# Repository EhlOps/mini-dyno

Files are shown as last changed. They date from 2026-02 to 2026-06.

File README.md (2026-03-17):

# Mini Dyno

### Overview

The mini dyno (dynamometer) is a tool created to measure the torque and power output of an engine or motor. The mechanical portion of the dyno functions as a water brake. This design is suited for engines up to 4 horsepower and is mainly used to measure the output of small engines used in RC cars.

An ESP32-C3 microcontroller reads a load cell (via HX711 ADC) and a Hall effect RPM sensor, converts the readings to torque (Nm) and RPM, then streams them over WiFi to an iOS companion app. The app plots a traditional dyno graph — torque and power vs RPM — in real time.

---

## System Architecture

```
Engine ──── Water Brake ──── Load Cell ──── HX711 ────┐
                  │                                   ESP32-C3 ── WiFi AP ── iPhone
              Hall Sensor (4 magnets/rev) ─────────────┘
```

| Measurement | Sensor | Pin |
|---|---|---|
| Force (→ Torque) | HX711 load cell ADC | PD_SCK: GPIO 7, DOUT: GPIO 6 |
| RPM | Digital Hall effect | GPIO 10 |
| Ready indicator | LED | GPIO 5 |

**Torque arm:** 100 mm (load cell to shaft centre)
**Torque (Nm):** `Force (N) × 0.1 m`
**Power (hp):** `Torque (Nm) × RPM × 2π / 60 / 745.7`

---

## Repository Structure

```
mini-dyno/
├── firmware/   — ESP-IDF project for ESP32-C3
└── software/   — iOS companion app (Xcode / SwiftUI)
```

See the README in each subdirectory for build and usage instructions.

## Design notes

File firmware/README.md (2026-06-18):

# mini-dyno firmware

Firmware for the **mini-dyno**, a small water-brake dynamometer. It runs on an
**ESP32-C3**, stands up an open Wi-Fi access point, and serves live torque/RPM
telemetry to connected clients over a tiny built-in MQTT broker. A phone or
laptop joins the AP, subscribes, and plots the dyno run in real time.

Written in async Rust (`no_std`) on [`esp-hal`] and [`embassy`].

[`esp-hal`]: https://docs.rs/esp-hal
[`embassy`]: https://embassy.dev

## Read the docs (the guided tour)

The whole codebase is documented as rustdoc — the module headers read top to
bottom as an explanation of *why* the firmware is shaped the way it is. The
best way to understand it is to generate the docs and browse them:

```sh
cargo doc --no-deps --open
```

This builds the API docs for just this crate and opens them in your browser
(`target/riscv32imc-unknown-none-elf/doc/firmware/index.html`). Drop
`--no-deps` if you also want the docs for `esp-hal`, `embassy`, `smoltcp`, etc.
linked inline — that's a much bigger build, but every type cross-links to its
upstream definition.

Suggested reading order, following the links as you go:

1. **`firmware`** (crate root) — the one-paragraph map of the modules.
2. **`firmware::net`** — bringing up the Wi-Fi AP and the `embassy-net` stack;
   start with the `Net` type.
3. **`firmware::net::mqtt`** — the payload-agnostic MQTT 3.1.1/5 broker, its
   concurrency model (`Feed` / `Watch`), and the per-connection state machine.
4. **`firmware::drivers`** — the sensor drivers and their read loops:
   `drivers::hx711` (load-cell ADC, bit-banged) and `drivers::hall_effect`
   (interrupt-driven RPM pickup), each republishing on a `Signal`.
5. **`firmware::telemetry`** — the `Telemetry` sample type, its JSON wire
   format, and the producer task that latches the driver signals and feeds the
   broker.
6. **`firmware::macros`** — `mk_static!`, the `'static`-allocation helper the
   embassy tasks lean on.

> The binary entry point (`src/bin/main.rs`) is a separate bin crate, so it
> isn't part of the `firmware` library docs above. Its boot sequence is
> documented in the file's own `//!` header.

## Build & flash

Prerequisites:

- A Rust toolchain — the pinned channel and the RISC-V target are declared in
  [`rust-toolchain.toml`](rust-toolchain.toml) and installed automatically by `rustup`.
- [`espflash`](https://github.com/esp-rs/espflash) (`cargo install espflash`)
  for flashing over USB; it's already wired up as the cargo runner.

```sh
cargo build --release        # compile
cargo run                    # flash + monitor (defmt) over USB
cargo run --release          # same, optimized
```

The target (`riscv32imc-unknown-none-elf`) and the `espflash` runner are
configured in [`.cargo/config.toml`](.cargo/config.toml), so plain `cargo run`
just works. You can also simulate the firmware without hardware via
[Wokwi](https://wokwi.com) — see [`wokwi.toml`](wokwi.toml) and
[`diagram.json`](diagram.json).

## Connecting a client

1. Join the open Wi-Fi network **`mini-dyno`**.
2. Point an MQTT client at `192.168.1.1:1883` and subscribe to `dyno/telemetry`.
3. You'll receive a JSON payload per sample: `{"torque":<n.nn>,"rpm":<n>}`.

## Status

Both sensors are wired in and read live: the hall-effect driver
(`drivers::hall_effect`, GPIO10) reports real RPM, and the HX711 load-cell
driver (`drivers::hx711`, GPIO6/7) streams real ADC samples. **Calibration is
still pending** — `telemetry::producer` currently passes the raw 24-bit HX711
word straight through as the `torque` field, so that number is a placeholder
until an offset/scale (tare + N·m per count) is applied.

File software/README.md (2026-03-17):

# Dyno Monitor — iOS App

iOS companion app for the mini-dyno dynamometer. Connects to the ESP32 over WiFi, streams live torque and RPM readings, plots a traditional dyno graph (torque + power vs RPM) in real time, and exports session data as CSV or PNG.

## Requirements

- iOS 16+
- Xcode 15+
- mini-dyno ESP32 device running the firmware

## How It Works

The ESP32 runs a WiFi access point (`mini-dyno`, open network) and a WebSocket server. The app connects to `ws://192.168.4.1/ws` and receives JSON frames at 50 Hz:

```json
{"torque": 12.45, "rpm": 3200}
```

| Field | Type | Description |
|---|---|---|
| `torque` | float | Torque in Newton-metres |
| `rpm` | float | Engine speed in RPM |

Power is computed in the app: `P (hp) = torque (Nm) × rpm × 2π / 60 / 745.7`

The app plots both torque (Nm, red) and power (hp, blue) against RPM on the same chart, matching a traditional dyno sheet.

## Getting Started

1. Flash the ESP32 firmware (see `../firmware/`)
2. On your iPhone/iPad, go to **Settings → Wi-Fi** and join the `mini-dyno` network
3. Open the app — the connection indicator turns green when the device is reachable
4. Tap **Start** to begin recording, **Stop** to end the session

## App Structure

```
software/
├── Models/
│   ├── DynoDataPoint.swift     — single sample: rpm, torqueNm, computed powerHp
│   └── DynoSession.swift       — recording session; tracks peak torque, peak power, RPM at peaks
├── Services/
│   ├── WebSocketService.swift  — URLSession WebSocket client; parses {"torque","rpm"} frames
│   ├── NetworkMonitor.swift    — polls GET /ping every 2 s to track connectivity
│   └── DataExporter.swift      — exports CSV and graph PNG to the temp directory
├── View Models/
│   └── DynoViewModel.swift     — app state; bridges WebSocket → session data points
├── Utilities/
│   └── AppConfiguration.swift  — network URLs, timing constants, feature flags
└── Views/
    ├── ContentView.swift        — adaptive layout: graph + controls
    ├── ConnectionStatusView.swift
    ├── DynoGraphView.swift      — SwiftUI Charts: torque (red) + power (blue) vs RPM
    ├── StatsView.swift          — peak torque, peak power (with RPM subtitles), point count
    ├── DetailedStatsView.swift  — full run report with export button
    ├── SavedSessionsView.swift  — history list; swipe to delete or export
    └── SettingsView.swift       — edit WebSocket/ping URLs; reset to defaults
```

## UI Overview

The main screen uses an adaptive two-column layout in landscape:

- **Left** — live connection status badge + dyno graph
- **Right** — Start / Stop / Clear / Stats buttons

The toolbar provides access to **Settings** (gear icon, top-left) and **Session History** (clock icon, top-right).

### Settings

| Setting | Default |
|---|---|
| WebSocket URL | `ws://192.168.4.1/ws` |
| Device Ping URL | `http://192.168.4.1/ping` |

### Session History

Completed sessions are listed in reverse chronological order showing peak torque, peak power, and point count. Swipe left to **Export** (CSV + graph PNG) or swipe right to **Delete**.

## Export Format

**CSV** — one row per sample, plus a summary block:

```
Timestamp,RPM,Torque (Nm),Power (hp)
12:34:56.001,1200,42.30,9.65
12:34:56.021,1260,44.80,10.72
...

Summary
Peak Torque (Nm),82.0
Peak Power (hp),38.42
RPM at Peak Torque,3500
RPM at Peak Power,4800
```

**Graph PNG** — 1200×800 px at 2× scale (2400×1600 effective).

## Debug Build

In debug builds a **Test Data** button appears on the main screen. It generates a simulated dyno pull from 1000 to 6000 RPM with a Gaussian torque curve peaking at 85 Nm near 3500 RPM, so the UI can be exercised without hardware.

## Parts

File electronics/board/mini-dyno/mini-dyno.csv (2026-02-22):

Reference | Qty | Value | DNP | Exclude from BOM | Exclude from Board | Footprint | Datasheet
C1,C5,C6,C8,C9 | 5 | 10uF |  |  |  | Capacitor_SMD:C_0805_2012Metric | ~
C2,C4,C7,C10,C12 | 5 | 0.1uF |  |  |  | Capacitor_SMD:C_0805_2012Metric | ~
C3 | 1 | 1uF |  |  |  | Capacitor_SMD:C_0805_2012Metric | ~
C11 | 1 | 35ZLH100MEFC6.3X11 |  |  |  | easyeda2kicad:CAP-TH_BD6.3-P2.50-D1.0-FD | https://lcsc.com/product-detail/Aluminum-Electrolytic-Capacitors-Leaded_Rubycon_35ZLH100MEFC6-3X1_100uF-107-20-35V_C109392.html
D1 | 1 | ESD122DMYR |  |  |  | easyeda2kicad:X2SON-3_L1.3-W0.6-L
D2 | 1 | SMBJ5.0A_C83333 |  |  |  | easyeda2kicad:SMB_L4.6-W3.6-LS5.3-RD | https://lcsc.com/product-detail/Others_Littelfuse_SMBJ5-0A_Littelfuse-SMBJ5-0A_C83333.html
D3 | 1 | LED_ON |  |  |  | LED_THT:LED_D5.0mm | ~
D4 | 1 | LED_STATUS |  |  |  | LED_THT:LED_D5.0mm | ~
D5 | 1 | SS310_C14281 |  |  |  | easyeda2kicad:SMB_L4.6-W3.6-LS5.3-RD | https://lcsc.com/product-detail/Schottky-Barrier-Diodes-SBD_SS310_C14281.html
F1 | 1 | TLC-PSML400 |  |  |  | easyeda2kicad:F0805
J1 | 1 | Conn_01x04_Pin |  |  |  | Connector_PinHeader_2.54mm:PinHeader_1x04_P2.54mm_Horizontal | ~
J2 | 1 | Conn_01x03_Pin |  |  |  | Connector_PinHeader_2.54mm:PinHeader_1x03_P2.54mm_Horizontal | ~
MOTOR1 | 1 | 916-252A2023Y10200 |  |  |  | easyeda2kicad:USB-A-TH_916-352A102BY10200
R1,R5,R6,R7,R11,R13 | 6 | 10kΩ |  |  |  | Resistor_SMD:R_0805_2012Metric | ~
R2,R3,R4,R9 | 4 | 5.1kΩ |  |  |  | Resistor_SMD:R_0805_2012Metric | ~
R8,R10 | 2 | 1MΩ |  |  |  | Resistor_SMD:R_0805_2012Metric | ~
R12,R14,R15,R16 | 4 | 100Ω |  |  |  | Resistor_SMD:R_0805_2012Metric | ~
SW1,SW2 | 2 | SW_Push |  |  |  | Button_Switch_SMD:SW_Push_1P1T_NO_E-Switch_TL3301NxxxxxG | ~
U1 | 1 | ESP32-C3-MINI-1 |  |  |  | PCM_Espressif:ESP32-C3-MINI-1 | https://www.espressif.com/sites/default/files/documentation/esp32-c3-mini-1_datasheet_en.pdf
U2 | 1 | TLV75733PDBVR |  |  |  | easyeda2kicad:SOT-23-5_L2.9-W1.6-P0.95-LS2.8-BL | https://lcsc.com/product-detail/New-Arrivals_Texas-Instruments-Texas-Instruments-TLV75733PDBVR_C485517.html
U4 | 1 | HX711_C6705483 |  |  |  | easyeda2kicad:SOP-16_L10.0-W3.9-P1.27-LS6.0-BL
USB1,USB3 | 2 | MC-710A |  |  |  | easyeda2kicad:USB-C-TH_MC-710A

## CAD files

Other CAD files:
mechanical/parts/Rotor.step
mechanical/parts/Rotor Housing.step
mechanical/parts/Stator.step
mechanical/parts/Bearing Housing.step
mechanical/parts/Holder.step
mechanical/parts/Load Cell Base.step
mechanical/parts/Collar.step

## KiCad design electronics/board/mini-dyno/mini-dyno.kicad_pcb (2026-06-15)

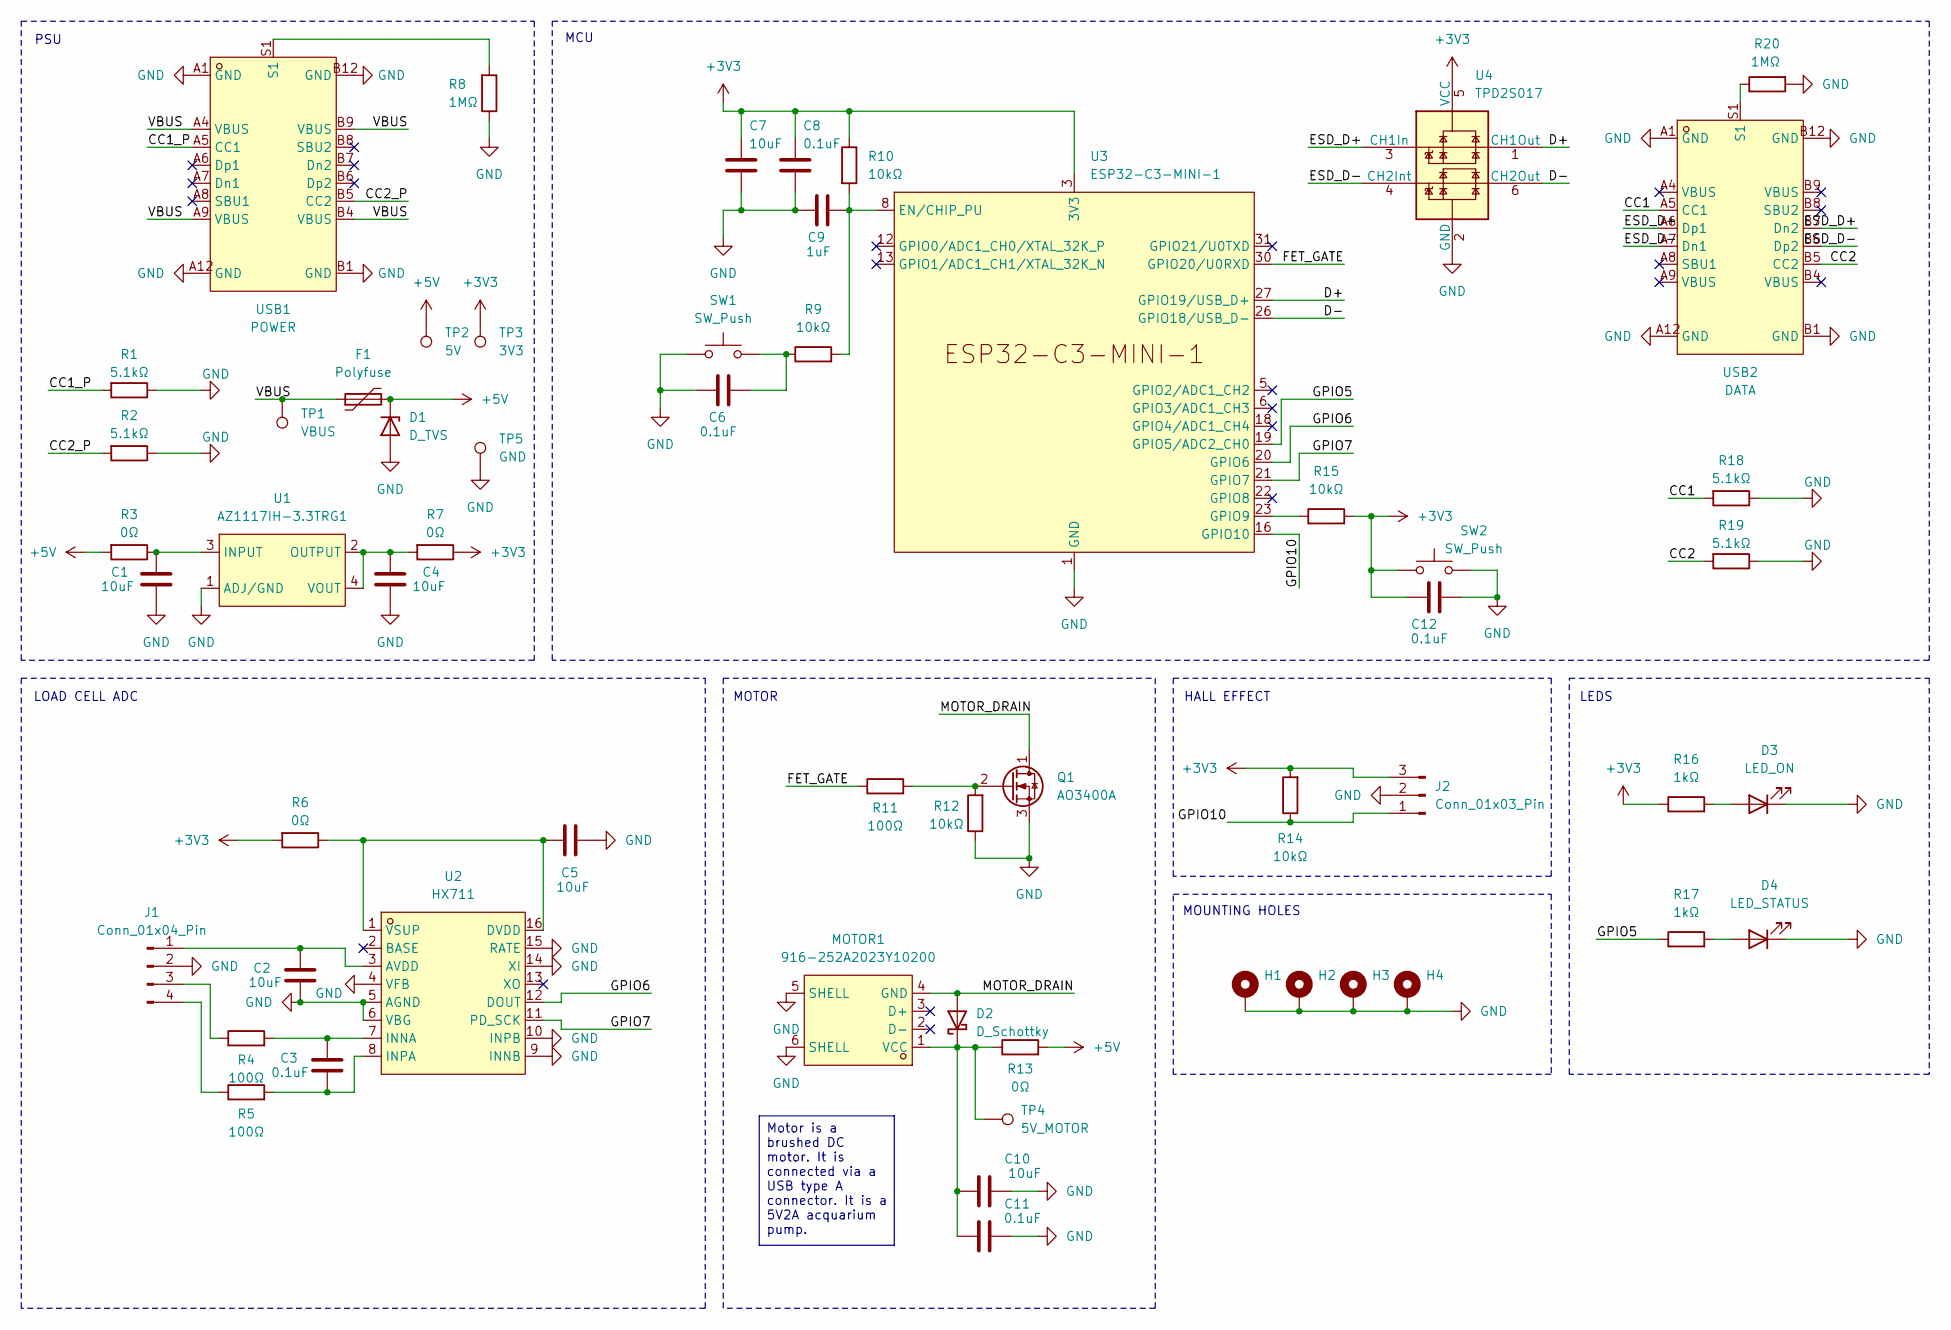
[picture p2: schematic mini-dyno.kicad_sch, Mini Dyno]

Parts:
C1, C2, C4, C5, C7, C10: 10uF; C_0805_2012Metric
C3, C6, C8, C11, C12: 0.1uF; C_0805_2012Metric
C9: 1uF; C_0805_2012Metric
D1: D_TVS; D_SMB
D2: D_Schottky; D_SMB
D3: LED_ON; LED_D5.0mm
D4: LED_STATUS; LED_D5.0mm
F1: Polyfuse; Fuse_0805_2012Metric_Pad1.15x1.40mm_HandSolder
H1, H2, H3, H4: MountingHole_3.2mm_M3_Pad
J1: Conn_01x04_Pin; PinHeader_1x04_P2.54mm_Horizontal
J2: Conn_01x03_Pin; PinHeader_1x03_P2.54mm_Horizontal
MOTOR1: 916-252A2023Y10200; USB-A-TH_916-352A102BY10200; LCSC Part C2763312
Q1: AO3400A; SOT-23_Handsoldering
R1, R2, R18, R19: 5.1kΩ; R_0805_2012Metric
R3, R6, R7, R13: 0Ω; R_1206_3216Metric_Pad1.30x1.75mm_HandSolder
R4, R5, R11: 100Ω; R_0805_2012Metric
R8, R20: 1MΩ; R_0805_2012Metric
R9, R10, R12, R14, R15: 10kΩ; R_0805_2012Metric
R16, R17: 1kΩ; R_0805_2012Metric
SW1, SW2: SW_Push; SW_Push_1P1T_NO_E-Switch_TL3301NxxxxxG
TP1: VBUS; TestPoint_THTPad_2.0x2.0mm_Drill1.0mm
TP2: 5V; TestPoint_THTPad_2.0x2.0mm_Drill1.0mm
TP3: 3V3; TestPoint_THTPad_2.0x2.0mm_Drill1.0mm
TP4: 5V_MOTOR; TestPoint_THTPad_2.0x2.0mm_Drill1.0mm
TP5: GND; TestPoint_THTPad_2.0x2.0mm_Drill1.0mm
U1: AZ1117IH-3.3TRG1; SOT-223-4_L6.5-W3.5-P2.30-LS7.0-BR; MPN AZ1117IH-3.3TRG1; LCSC Part C108495
U2: HX711; SOP-16_L10.0-W3.9-P1.27-LS6.0-BL; LCSC Part C6705483
U3: ESP32-C3-MINI-1
U4: TPD2S017; SOT-23-6
USB1: POWER; USC-C-SMD_USB4085-GF-A; MPN USB4085-GF-A; LCSC Part C7095263
USB2: DATA; USC-C-SMD_USB4085-GF-A; MPN USB4085-GF-A; LCSC Part C7095263

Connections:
+3V3: C7.1, C8.1, C12.1, J2.3, R6.2, R7.1, R10.1, R14.2, R15.2, R16.1, SW2.1, TP3.1 (1_1), U3.3 (3V3), U4.5 (VCC); also elsewhere on the board
+5V: D1.1 (K), F1.2, R3.2, R13.2, TP2.1 (1_1)
/CC1: R18.2, USB2.A5 (CC1)
/CC1_P: R1.2, USB1.A5 (CC1)
/CC2: R19.2, USB2.B5 (CC2)
/CC2_P: R2.2, USB1.B5 (CC2)
/D+: U3.27 (GPIO19/USB_D+), U4.1 (CH1Out)
/D-: U3.26 (GPIO18/USB_D-), U4.6 (CH2Out)
/ESD_D+: U4.3 (CH1In), USB2.A6 (Dp1), USB2.B7 (Dn2)
/ESD_D-: U4.4 (CH2Int), USB2.A7 (Dn1), USB2.B6 (Dp2)
/FET_GATE: R11.1, U3.30 (GPIO20/U0RXD)
/GPIO5: R17.1, U3.19 (GPIO5/ADC2_CH0)
/GPIO6: U2.12 (DOUT), U3.20 (GPIO6)
/GPIO7: U2.11 (PD_SCK), U3.21 (GPIO7)
/GPIO10: J2.1, R14.1, U3.16 (GPIO10)
/MOTOR_DRAIN: D2.2 (A), MOTOR1.4 (GND), Q1.1 (D)
/VBUS: F1.1, TP1.1 (1_1), USB1.A4 (VBUS), USB1.A9 (VBUS), USB1.B4 (VBUS), USB1.B9 (VBUS)
GND: C1.2, C2.1, C4.2, C5.1, C6.1, C7.2, C8.2, C9.1, C10.1, C11.1, C12.2, D1.2 (A), D3.1 (K), D4.1 (K), H1.1 (1_1), H2.1 (1_1), H3.1 (1_1), H4.1 (1_1), J1.2, J2.2, MOTOR1.5 (SHELL), MOTOR1.6 (SHELL), Q1.3 (S), R1.1, R2.1, R8.1, R12.1, R18.1, R19.1, R20.2, SW1.1, SW2.2, TP5.1 (1_1), U1.1 (ADJ/GND), U2.4 (VFB), U2.5 (AGND), U2.6 (VBG), U2.9 (INNB), U2.10 (INPB), U2.14 (XI), U2.15 (RATE), U3.1 (GND), U3.2 (GND), U3.11 (GND), U3.14 (GND), U3.36 (GND), U3.37 (GND), U3.38 (GND), U3.39 (GND), U3.40 (GND), U3.41 (GND), U3.42 (GND), U3.43 (GND), U3.44 (GND), U3.45 (GND), U3.46 (GND), U3.47 (GND), U3.48 (GND), U3.49 (GND), U3.50 (GND), U3.51 (GND), U3.52 (GND), U3.53 (GND), U4.2 (GND), USB1.A1 (GND), USB1.A12 (GND), USB1.B1 (GND), USB1.B12 (GND), USB2.A1 (GND), USB2.A12 (GND), USB2.B1 (GND), USB2.B12 (GND); also elsewhere on the board
unnamed 18: C6.2, R9.1, SW1.2; also elsewhere on the board
unnamed: C10.2, C11.2, D2.1 (K), MOTOR1.1 (VCC), R13.1, TP4.1 (1_1)
unnamed: D3.2 (A), R16.2
unnamed: D4.2 (A), R17.2
unnamed: C2.2, J1.1, U2.3 (AVDD)
unnamed: J1.3, R4.1
unnamed: J1.4, R5.1
unnamed: Q1.2 (G), R11.2, R12.2
unnamed: R8.2, USB1.S1
unnamed: R20.1, USB2.S1
unnamed: C1.1, R3.1, U1.3 (INPUT)
unnamed: C4.1, R7.2, U1.2 (OUTPUT), U1.4 (VOUT)
unnamed: C5.2, R6.1, U2.1 (VSUP), U2.16 (DVDD)
unnamed: C3.2, R4.2, U2.7 (INNA)
unnamed: C3.1, R5.2, U2.8 (INPA)
unnamed: C9.2, R9.2, R10.2, U3.8 (EN/CHIP_PU)
unnamed: R15.1, U3.23 (GPIO9)

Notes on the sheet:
PSU
HALL EFFECT
LEDS
MOUNTING HOLES
MCU
MOTOR
LOAD CELL ADC
Motor is a brushed DC motor. It is connected via a USB type A connector. It is a 5V2A acquarium pump.

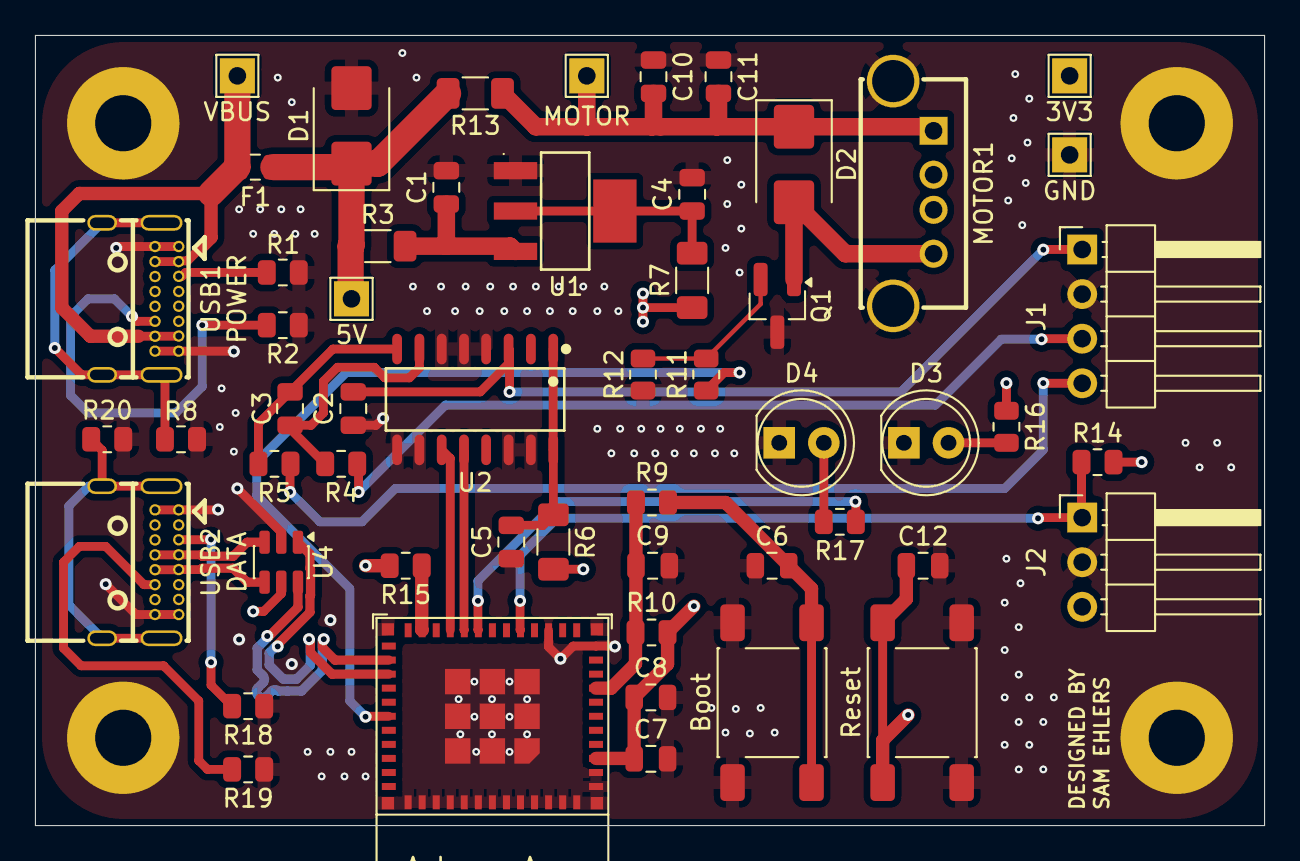
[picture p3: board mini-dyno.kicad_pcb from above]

Board: 4 copper layers, 70.0 x 45.0 mm, 58 parts (0 on the bottom side), 35 nets.

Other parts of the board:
Boot: SW_Push; SW_Push_1P1T_NO_E-Switch_TL3301NxxxxxG
Reset: SW_Push; SW_Push_1P1T_NO_E-Switch_TL3301NxxxxxG

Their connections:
+3V3: Reset.1; also elsewhere on the board
GND: Boot.1, Reset.2; also elsewhere on the board
unnamed 18: Boot.2; also elsewhere on the board

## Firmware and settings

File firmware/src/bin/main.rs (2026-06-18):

#![no_std]
#![no_main]
#![deny(
    clippy::mem_forget,
    reason = "mem::forget is generally not safe to do with esp_hal types, especially those \
    holding buffers for the duration of a data transfer."
)]
#![deny(clippy::large_stack_frames)]

//! Binary entry point for the mini-dyno firmware.
//!
//! Boots the ESP32-C3: configures clocks and heap, starts the `esp-rtos`
//! executor, then brings up the network and telemetry pipeline defined in the
//! [`firmware`] library crate:
//!
//! 1. [`Net::new`](firmware::net::Net::new) opens the `mini-dyno` Wi-Fi access
//!    point and a static IPv4 stack at `192.168.1.1`.
//! 2. [`mqtt::start`](firmware::net::mqtt::start) launches the MQTT broker on
//!    TCP `1883`, publishing under [`telemetry::TOPIC`](firmware::telemetry::TOPIC).
//! 3. The sensor read loops
//!    ([`hx711_read_loop`](firmware::drivers::hx711_read_loop) on GPIO6/7 and
//!    [`hall_effect_read_loop`](firmware::drivers::hall_effect_read_loop) on
//!    GPIO10) are spawned, each publishing its latest reading on a `Signal`.
//! 4. [`telemetry::start`](firmware::telemetry::start) spawns the producer that
//!    latches those signals and pushes torque/RPM samples onto the shared
//!    [`Feed`].
//!
//! After setup `main` idles forever; all real work runs in the spawned tasks.

use core::future;
use defmt::{error, info};
use embassy_executor::Spawner;
use esp_hal::clock::CpuClock;
use esp_hal::gpio::Io;
use esp_hal::timer::timg::TimerGroup;
use esp_println as _;
use firmware::mk_static;
use firmware::net::Net;
use firmware::net::mqtt::{self, Feed};
use firmware::telemetry;
use firmware::drivers::hall_effect::{HallEffectSensor, RPMSignal};
use firmware::drivers::hx711::{HX711, LoadCellSignal};
use firmware::drivers::{hall_effect_read_loop, hx711_read_loop};

#[panic_handler]
fn panic(panic_info: &core::panic::PanicInfo) -> ! {
    error!("{}", panic_info);
    loop {}
}

extern crate alloc;

// This creates a default app-descriptor required by the esp-idf bootloader.
// For more information see: <https://docs.espressif.com/projects/esp-idf/en/stable/esp32/api-reference/system/app_image_format.html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>
esp_bootloader_esp_idf::esp_app_desc!();

#[allow(
    clippy::large_stack_frames,
    reason = "it's not unusual to allocate larger buffers etc. in main"
)]
#[esp_rtos::main]
async fn main(spawner: Spawner) -> ! {
    // generator version: 1.3.0
    // generator parameters: --chip esp32c3 -o esp32c3-mini-1 -o unstable-hal -o alloc -o wifi -o embassy -o defmt -o wokwi -o vscode

    let config = esp_hal::Config::default().with_cpu_clock(CpuClock::max());
    let peripherals = esp_hal::init(config);

    esp_alloc::heap_allocator!(#[esp_hal::ram(reclaimed)] size: 64 * 1024);
    esp_alloc::heap_allocator!(size: 36 * 1024);

    let timg0 = TimerGroup::new(peripherals.TIMG0);
    let sw_interrupt =
        esp_hal::interrupt::software::SoftwareInterruptControl::new(peripherals.SW_INTERRUPT);
    esp_rtos::start(timg0.timer0, sw_interrupt.software_interrupt0);

    info!("Embassy initialized!");

    let net = Net::new(peripherals.WIFI, "mini-dyno", "192.168.1.1");
    let stack = net.run(spawner).await;

    // Bring up the MQTT broker (3.1.1/5) and the telemetry feed it serves.
    // Clients connect to tcp 192.168.1.1:1883 and subscribe to "dyno/telemetry".
    let feed = mk_static!(Feed, Feed::new());
    mqtt::start(
        spawner,
        stack,
        feed,
        mqtt::Config {
            port: 1883,
            topic: telemetry::TOPIC,
        },
    );

    let hx711 = mk_static!(HX711, HX711::new(peripherals.GPIO6, peripherals.GPIO7));
    let lc_sig = mk_static!(LoadCellSignal, LoadCellSignal::new());
    spawner.spawn(hx711_read_loop(hx711, lc_sig).unwrap());

    let mut io = Io::new(peripherals.IO_MUX);
    let hall = mk_static!(
        HallEffectSensor,
        HallEffectSensor::new(&mut io, peripherals.GPIO10, 4)
    );
    let rpm_sig = mk_static!(RPMSignal, RPMSignal::new());
    spawner.spawn(hall_effect_read_loop(hall, rpm_sig).unwrap());

    telemetry::start(spawner, feed, lc_sig, rpm_sig);

    // All real work runs in the spawned tasks above. Park main forever: this
    // future never resolves, so it satisfies `-> !` without ever waking the CPU.
    future::pending().await
}

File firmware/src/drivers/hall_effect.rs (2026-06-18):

//! Hall-effect RPM sensor driver.
//!
//! A magnet passing the sensor pulls the input low once per magnet; with
//! `divider` magnets evenly spaced around the rotor we see `divider` pulses per
//! revolution. We count rising edges in a GPIO interrupt and convert the count
//! accumulated over a fixed window into an RPM figure.
//!
//! The pin is configured with no internal pull (`InputConfig::default()`): the
//! sensor's open-drain output relies on an external pull-up to idle high, so a
//! passing magnet drives the line low and the trailing rising edge — the magnet
//! leaving — is what we count.
//!
//! esp-hal 1.1 exposes no hardware glitch filter for the C3's GPIOs, so we
//! debounce in software: any edge arriving sooner than `MIN_PULSE_INTERVAL_US`
//! after the previous accepted one is treated as switch bounce / noise and
//! dropped.

use core::cell::RefCell;

use critical_section::Mutex;
use embassy_sync::blocking_mutex::raw::CriticalSectionRawMutex;
use embassy_sync::signal::Signal;
use embassy_time::{Duration, Instant, Ticker};
use esp_hal::gpio::{Event, Input, InputConfig, InputPin, Io};
use esp_hal::handler;

/// One-way channel carrying the latest RPM figure from the read loop to any
/// consumer. Interior-mutable, so it can be shared as `&'static`.
pub type RPMSignal = Signal<CriticalSectionRawMutex, u32>;

/// Sampling window. Pulses are counted over this interval, then converted to
/// RPM. Shorter windows react faster but quantize harder at low RPM (fewer
/// pulses per window); 50 ms matches the telemetry cadence.
const WINDOW_MS: u16 = 50;

/// Software glitch filter: edges closer together than this are bounce/noise and
/// are ignored. Set it just below the shortest real pulse spacing at your max
/// RPM. e.g. 4 magnets @ 12000 RPM => 800 pulses/s => 1250 µs spacing, so
/// 300 µs leaves comfortable margin without dropping legitimate pulses.
const MIN_PULSE_INTERVAL_US: u16 = 300;

/// State shared between the GPIO interrupt handler and the sampler. The handler
/// is registered globally (per-pin handlers don't exist), so we stash the pin
/// here to clear its interrupt flag, the last accepted edge time for
/// debouncing, and the running pulse count.
///
/// The count lives here rather than in an atomic because the C3 (rv32imc) has
/// no native atomic read-modify-write; the critical section guards it instead.
struct IsrState {
    pin: Input<'static>,
    last_edge: Instant,
    pulses: u32,
}

static STATE: Mutex<RefCell<Option<IsrState>>> = Mutex::new(RefCell::new(None));

/// Global GPIO interrupt handler. Counts debounced rising edges.
#[handler]
fn hall_isr() {
    critical_section::with(|cs| {
        let mut guard = STATE.borrow_ref_mut(cs);
        let Some(state) = guard.as_mut() else { return };
        if !state.pin.is_interrupt_set() {
            return;
        }
        state.pin.clear_interrupt(); // re-arm for the next edge

        let now = Instant::now();
        if (now - state.last_edge).as_micros() >= MIN_PULSE_INTERVAL_US as u64 {
            state.last_edge = now;
            state.pulses = state.pulses.saturating_add(1);
        }
    });
}

pub struct HallEffectSensor {
    /// Pulses (magnets) per revolution.
    divider: u32,
    /// Drives the fixed sampling cadence in [`read_signal`](Self::read_signal).
    ticker: Ticker,
}

impl HallEffectSensor {
    /// Wire the pin to the GPIO interrupt and arm rising-edge detection.
    ///
    /// `io` is the [`Io`] driver from `main`; the interrupt handler is global,
    /// so this must be called once.
    pub fn new(io: &mut Io<'_>, data: impl InputPin + 'static, divider: u32) -> Self {
        let mut pin = Input::new(data, InputConfig::default());

        io.set_interrupt_handler(hall_isr);
        critical_section::with(|cs| {
            pin.listen(Event::RisingEdge);
            STATE.borrow_ref_mut(cs).replace(IsrState {
                pin,
                last_edge: Instant::now(),
                pulses: 0,
            });
        });

        Self {
            divider,
            ticker: Ticker::every(Duration::from_millis(WINDOW_MS as u64)),
        }
    }

    /// Await one sampling window, then return the RPM measured over it.
    ///
    /// Drains the pulse counter atomically (read-and-reset in one op, so edges
    /// landing between the read and the reset are never lost) and converts the
    /// count to RPM:
    ///
    /// `rpm = (pulses / divider) / (window_s) * 60`
    pub async fn read_signal(&mut self) -> u32 {
        self.ticker.next().await;

        // Read-and-reset the count accumulated over this window in one critical
        // section, so edges landing mid-drain are counted against the next one.
        let pulses = critical_section::with(|cs| {
            STATE
                .borrow_ref_mut(cs)
                .as_mut()
                .map_or(0, |state| core::mem::replace(&mut state.pulses, 0))
        });

        let rpm = (pulses as u64 * 60_000) / (self.divider as u64 * WINDOW_MS as u64);
        rpm as u32
    }
}

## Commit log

2026-02-04 Add FEA
    [691137710002.step, LDL1117S33R.step, dyno.kicad_sch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]
2026-02-04 Add FEA:
    [691137710002.step, LDL1117S33R.step, rotor.SLDPRT]
2026-02-22 Completed board
    [691137710002.step, LDL1117S33R.step, dyno.kicad_pcb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]
2026-02-22 Update PCB
    [mini-dyno-B_Cu.gbl, mini-dyno-B_Mask.gbs, mini-dyno-B_Paste.gbp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]
2026-02-23 Add solid parts
    [Bearing Housing.step, Collar.step, Holder.step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]
2026-06-04 Update PCB Layout
    [mini-dyno.kicad_pcb, mini-dyno.kicad_sch]
2026-06-05 Update Layout
    [mini-dyno.kicad_pcb]
2026-06-15 New Rust Firware
    [mini-dyno.kicad_pcb]
